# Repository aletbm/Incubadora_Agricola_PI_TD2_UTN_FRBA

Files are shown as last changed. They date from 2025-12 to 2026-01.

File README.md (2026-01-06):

# Incubadora Agrícola Automatica 🐣 

Este proyecto consiste en una **incubadora automatizada** diseñada para optimizar y controlar los parámetros críticos de temperatura y humedad necesarios para la eclosión de huevos de gallina (ciclo de 21 días). Utiliza un sistema embebido basado en **STM32** con **FreeRTOS** para la gestión de tareas en tiempo real y comunicación remota vía **Telegram**.

Desarrollado para la cátedra de **Técnicas Digitales II (2025-R4051) - UTN FRBA**.

---

## 🚀 Características Principales

* **Control Ambiental Automático**: Regulación de temperatura (lámpara halógena) y humedad (humidificador ultrasónico) mediante lógica de histéresis.
* **Ciclo de Incubación Programado**: Gestión automática de las etapas críticas:
    * **Día 0-18 (Incubación)**: Temperatura ~37.7°C, Humedad ~55%, Rotación activa.
    * **Día 18-21 (Eclosión)**: Temperatura ~37.2°C, Humedad ~70%, Rotación detenida.
* **Rotación Automática**: Sistema de bandeja rotatoria por motor para asegurar el desarrollo correcto del embrión.
* **Interfaz de Usuario (HMI)**: Pantalla LCD 16x2 y encoder rotativo KY-040 para navegación de menús.
* **Alertas Remotas**: Notificaciones de alarmas enviadas a un bot de Telegram mediante un módulo ESP32-C3.
* **Persistencia de Datos**: El progreso se guarda en la memoria Flash para retomar el ciclo tras cortes de energía.

---

## 📸 Galería del Proyecto

<p align="center"><i>Vista general del prototipo.</i></p>
<p align="center">
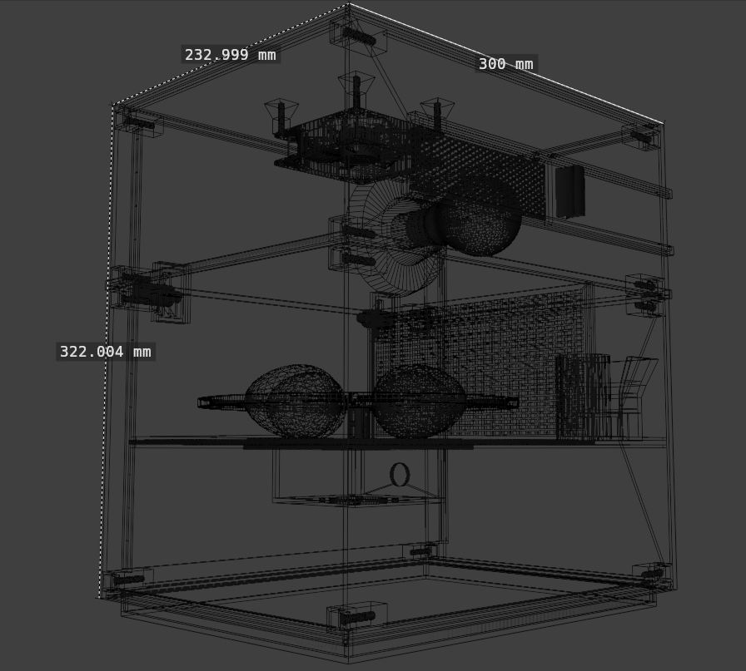
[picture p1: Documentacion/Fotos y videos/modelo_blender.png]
  
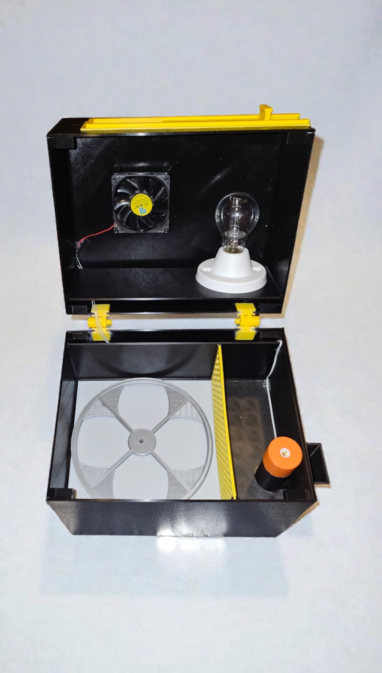
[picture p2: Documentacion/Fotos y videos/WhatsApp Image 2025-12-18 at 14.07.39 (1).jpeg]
  
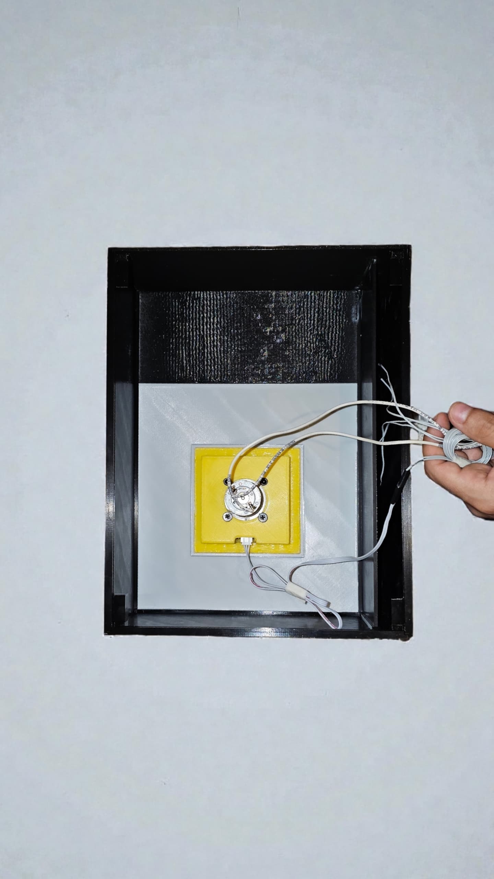
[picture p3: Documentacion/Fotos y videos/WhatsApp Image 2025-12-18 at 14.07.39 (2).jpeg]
Interior de la Incubadora
  
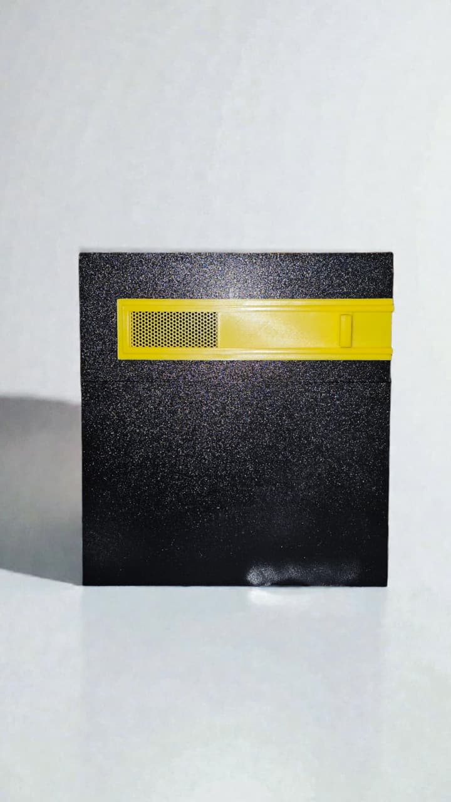
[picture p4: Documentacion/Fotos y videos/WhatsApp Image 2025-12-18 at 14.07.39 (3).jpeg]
Vista Frontal de la incubadora
  
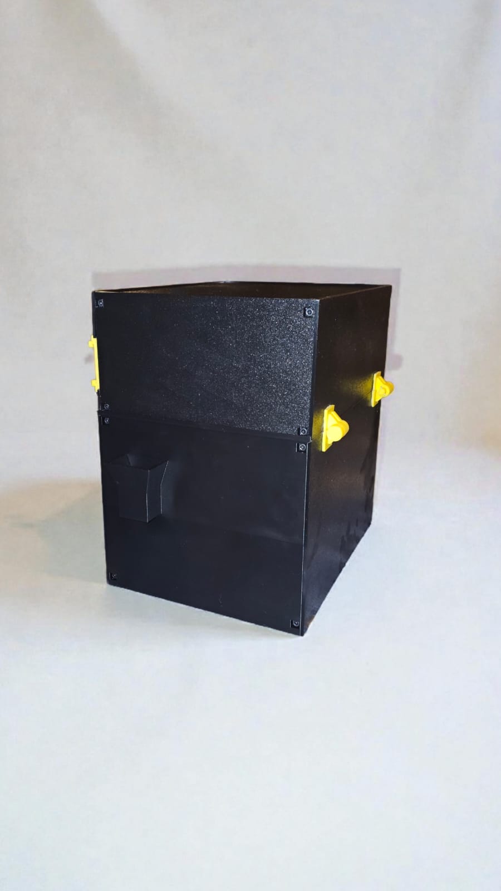
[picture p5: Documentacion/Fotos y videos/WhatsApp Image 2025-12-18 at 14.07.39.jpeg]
Vista oblicua de la Incubadora
  
</p>
<p align="center"><i>Vista del prototipo puesto a prueba.</i></p>

<p align="center">
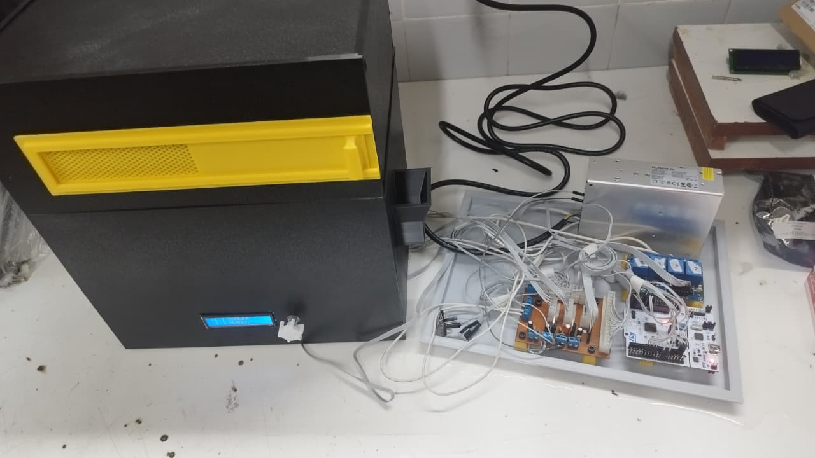
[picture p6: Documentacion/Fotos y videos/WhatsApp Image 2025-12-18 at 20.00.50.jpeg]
  
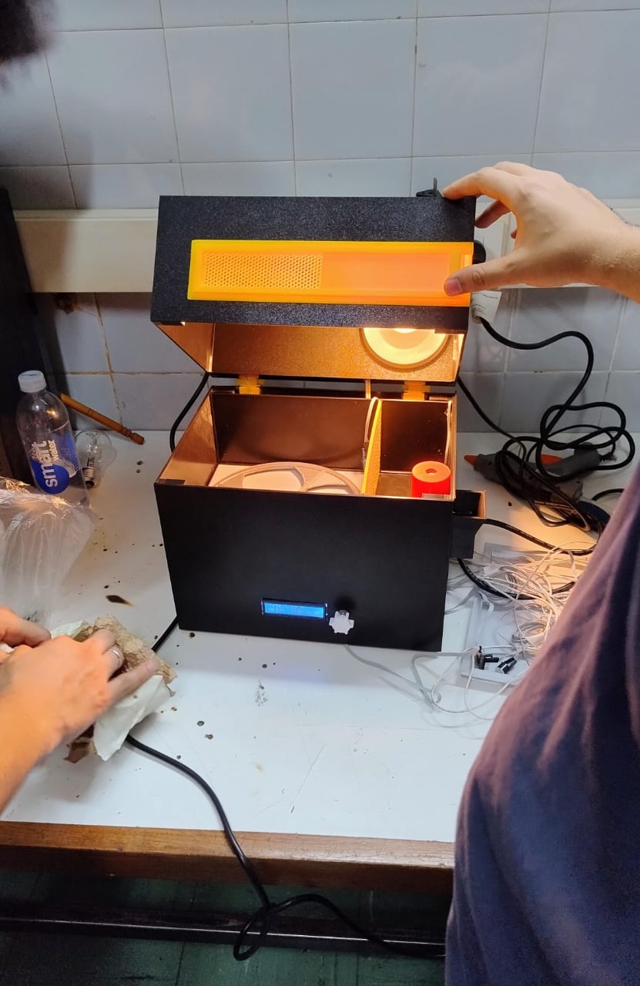
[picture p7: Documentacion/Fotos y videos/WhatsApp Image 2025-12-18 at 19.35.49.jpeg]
  
</p>

<p align="center"><i>Demo de la impresion 3D.</i></p>

https://github.com/user-attachments/assets/dec2215c-aceb-45dd-a1e9-db4e97dc1aad

---

## 🛠️ Hardware y Electrónica

El sistema central utiliza una placa **STM32 Nucleo-F446RE** conectada a un PCB diseñado en KiCad que gestiona tensiones de 3.3V, 5V, 12V y 220V.

### Componentes Clave:
* **Microcontroladores**: STM32F446RE y ESP32-C3 SuperMini (Bridge WiFi).
* **Sensores**: DHT11 para monitoreo ambiental.
* **Actuadores**: Módulo de 4 relés para lámpara, humidificador, cooler y motor.
* **Diseño de PCB**: Realizado íntegramente en **KiCad**.

---

## 💻 Arquitectura de Software (RTOS)

El firmware utiliza **FreeRTOS** para garantizar la ejecución concurrente de tareas críticas:

1.  **menuTask**: Gestión de la interfaz de usuario.
2.  **SensorTask**: Adquisición de datos del sensor DHT11.
3.  **ControlTask**: Lógica de control de temperatura y humedad.
4.  **MotorTask**: Control de tiempos de rotación.
5.  **Telegram/Bridge**: Comunicación serial con el ESP32 para alertas.

---

## 📁 Estructura del Repositorio

* `Incubadora_RTOS/`: Código fuente C para STM32 (STM32CubeIDE).
* `esp32c3-telegram/`: Firmware del módulo WiFi para Telegram.
* `Documentacion/`: Manuales de usuario, técnicos e informes.
* `PCB/`: Archivos de diseño electrónico (**KiCad**).
* `modelo_3D/`: Archivos de **Blender** y piezas **STL** para impresión.
* `Datasheets/`: Hojas de datos de los componentes.

---

## ⚙️ Configuración rápida

1.  **Carga de Firmware**: Flashear el proyecto de la carpeta `Incubadora_RTOS/` en la placa Nucleo.
2.  **Configuración WiFi**: Editar credenciales en `puenteTd2.ino` y cargar al ESP32.
3.  **Uso**: Iniciar el dispositivo, cargar agua en el tanque y seleccionar "INICIAR CICLO" desde el menú.

---

## 👥 Integrantes - Grupo 2
* **Carrettoni, Luciano**
* **Nanni, Franco**
* **Noé, Magdalena Cecilia**
* **Rios, Alexander Daniel**

**UTN FRBA - 2025**

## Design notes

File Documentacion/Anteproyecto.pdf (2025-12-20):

Grupo N°: | 2 | Año y División: | 2025 - R4051
Integrantes: | | 1 - CARRETTONI, LUCIANO 2 - NANNI, FRANCO 3 - NOÉ, MAGDALENA CECILIA 4 - RIOS, ALEXANDER DANIEL
| | Fecha: 25/06/25
Título del Proyecto: | Incubadora Agrícola

## Descripción

El proyecto se enfoca en el desarrollo de una incubadora de huevos de gallina, diseñada para ofrecer un control sobre las condiciones ambientales necesarias para una óptima eclosión. Permitirá a los usuarios configurar y monitorear de manera intuitiva parámetros críticos como la rotación de los huevos, la temperatura interna y la humedad relativa.

A través de su interfaz de usuario, los operadores podrán ajustar con exactitud cada uno de los factores ambientales, adaptándolos a las necesidades específicas de las diferentes etapas de incubación. Este nivel de personalización es crucial para maximizar la tasa de eclosión y asegurar el desarrollo saludable de los embriones.

La incubadora contará con un sistema de registro y almacenamiento de datos. La información detallada sobre los parámetros configurados y las mediciones ambientales se guardará en una tarjeta SD. Esto no solo facilita el monitoreo continuo y el seguimiento del progreso de la incubación, sino que también permite analizar el rendimiento de la incubadora a lo largo del tiempo. Los datos recopilados podrán ser utilizados para identificar patrones, optimizar futuras incubaciones y solucionar posibles problemas, contribuyendo así a una mejora constante en los resultados.

## Proceso

Ciclo de incubación:

El proceso de incubación de un huevo es un proceso que requiere de aproximadamente

### 21 días para concretar su ciclo, durante los cuales se debe mantener al huevo en un

espacio de temperatura y humedad controlada y de esta forma incrementar las probabilidades de una eclosión exitosa.
Dentro de este ciclo existen dos fases donde los parámetros ambientales sufren ligeras modificaciones, la primera fase culmina a los primeros 18 días de iniciar la incubación, donde:
Dia | Eventos principales
0 | Fecundación y formación del blastodisco
1 - 3 | Desarrollo del corazón, vasos sanguíneos, cabeza y ojos
4 - 7 | Formación del pico, alas, patas y plumas

| rudimentarias
8 - 14 | Desarrollo del esqueleto, órganos internos y primeros movimientos
14 - 18 | Posicionamiento del pollito, absorción de la yema y crecimiento final

Durante los últimos 3 días el embrión entra en la fase final durante los cuales se coloca en posición para romper el cascarón, orientando su cabeza hacia la cámara de aire y de esta forma lograr respirar aire a través de dicha cámara, y finalmente logra la eclosión del cascarón.

Los factores que influyen en el éxito de la eclosión involucran los siguiente parámetros:

Temperatura interna
Mantener una temperatura constante y controlada es crítico para el correcto desarrollo embrionario y la eclosión exitosa de los huevos. Este artefacto deberá ser capaz de mantener la temperatura a 37 °C
Consecuencias de errores:
- Temperatura alta: malformaciones, muerte embrionaria
- Temperatura baja: retraso o fallo en la eclosión.

Humedad interna
Durante los primeros 18 días, la humedad se debe mantener de 45% a 55%, y luego de 65% a 75% durante los últimos días antes de la eclosión.
Consecuencias de errores:
Humedad baja: polluelos deshidratados, cáscaras muy duras.
Humedad alta: exceso de líquido en el cascarón, ahogamiento.

Rotación/Inclinación de huevos
Los huevos deben ser rotados o ligeramente inclinados cada 2 o 3 horas durante los primeros 18 días. Los últimos 3 días los huevos no deben ser movidos. Con esto logramos evitar que el embrión se adhiera a la membrana de la cáscara.

Resumen de la variacion de parametros a lo largo del ciclo de incubación:

Periodo | Temperatura
ideal [°C]
Humedad | Movimiento del
huevo

Fase de
incubación

0 - 18 | 37.5 | 50% - 55% | Giro parcial o completo | Desarrollo completo
18 - 21 | 37.2 | 65% - 70% | Sin giro | Preparación y eclosión

## Incubadora

Respecto al diseño de la incubadora, tomamos como referencia ciertos modelos encontrados en internet.

La incubadora consta de un gabinete con aislación
térmica y una tapa superior desmontable, la cual
está equipada con visores para la inspección ocular del proceso. En su interior, una bandeja con sistema de rotación automática alberga los huevos. El ambiente se controla mediante una lámpara halógena para la calefacción y un ventilador que asegura la distribución homogénea de la temperatura y la humedad. Esta última es generada por un humidificador, cuyo depósito puede recargarse desde el exterior y cuenta con un indicador visual de nivel de agua.

El sistema de control electrónico se encuentra en
un | compartimento | separado | para | mayor
seguridad. A través de una pantalla digital, el

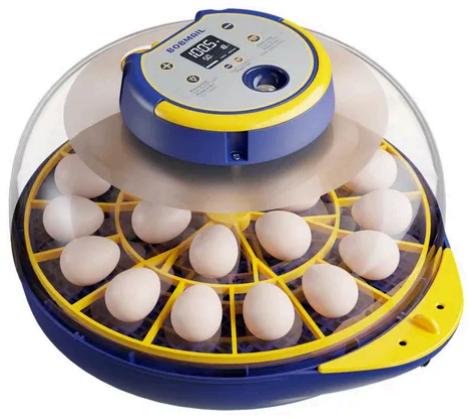
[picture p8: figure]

usuario puede supervisar y modificar los parámetros de incubación.

Además, en casos de emergencia una alarma sonora se activará si la temperatura o la humedad salen de los parámetros normales definidos.

A continuación se presenta un esquema preliminar del diseño.

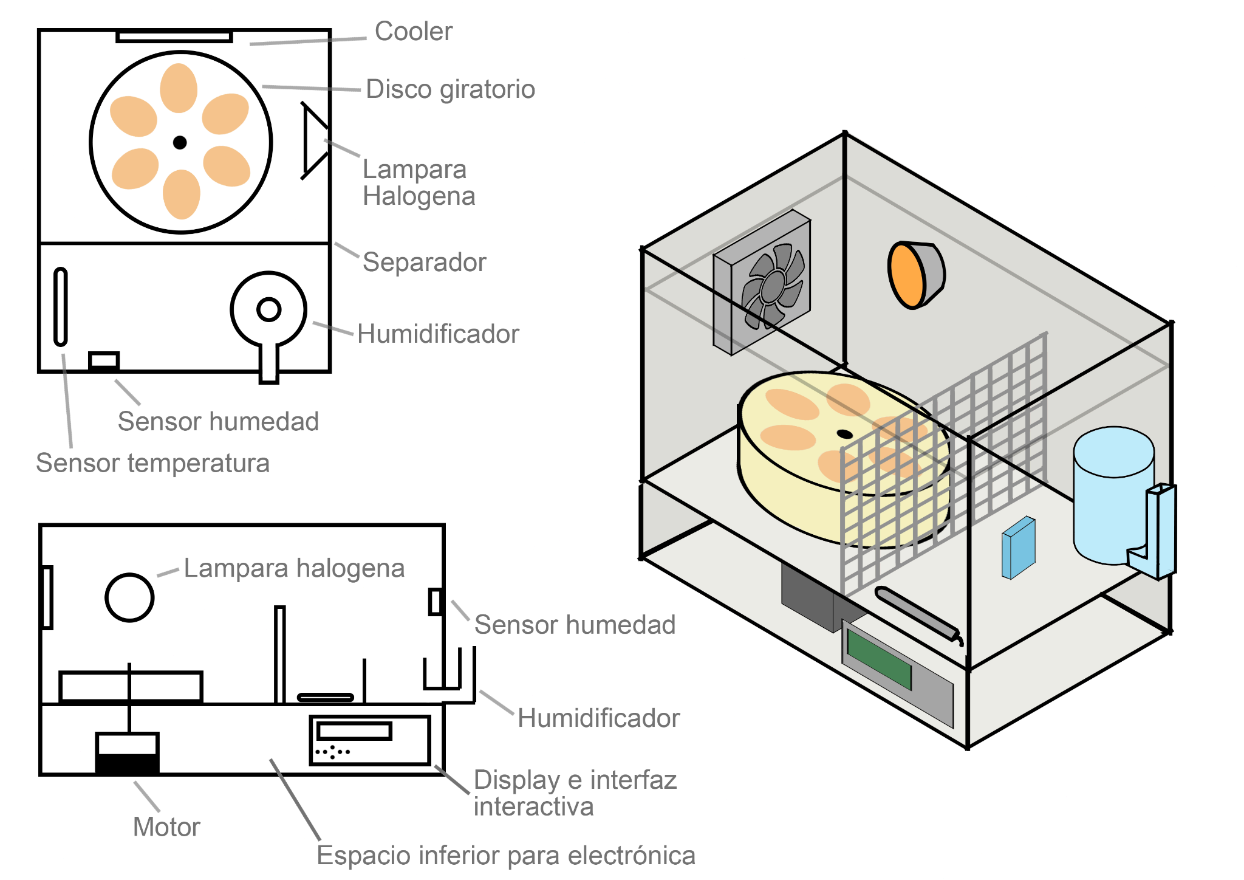
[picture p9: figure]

## Especificación técnica

El equipo contará con los siguientes elementos:
- Microcontrolador STM32F401RE
- Sensor de temperatura PT1000
- Sensor de humedad DHT11
- Motor paso a paso 28byj-48
- Display LCD 16X2 + keypad shield (botonera).
- Modulo tarjeta SD EM2003
- Fuente de alimentación
- Módulo relé
- Cooler.
- Lámpara halógena
- Humidificador
- Buzzer.

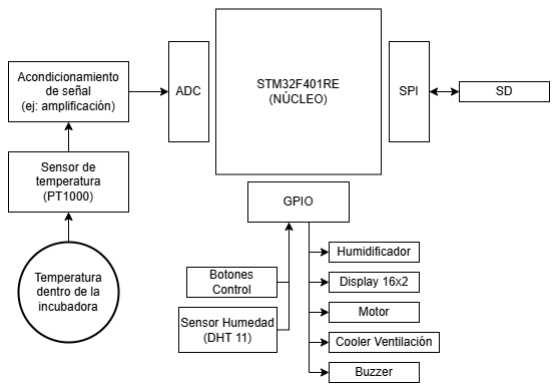
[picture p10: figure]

Motor 28BYJ-48 paso a paso, unipolar

Tensión de Funcionamiento: 5V DC Driver: ULN2003
Relación de Reducción: 1/64
Pasos por Vuelta: 4096
Par:34.3 mN·m

La selección del motor paso a paso 28BYJ-48 para el mecanismo de rotación se justifica por su capacidad para cumplir con los requerimientos de la aplicación económica. Este motor proporciona un torque de 34.3 mN·m, el cual es amplificado significativamente por el diseño del sistema. Tras calcular la carga máxima considerando un peso de 420 g para seis huevos y 300 g para la bandeja (total 0.72 kg) y estimar la fuerza de fricción, se determinó que se necesitaría un torque de aproximadamente 224 mN·m para mover la bandeja directamente.

Sin embargo, el diseño incorpora un sistema de engranajes externo (piñón-corona) que ofrece una ventaja mecánica de aproximadamente 20:1. Esta reducción reduce el par requerido en el eje del motor a solo 11.2 mN·m, un valor que es ampliamente cubierto por la capacidad del motor seleccionado, garantizando así un funcionamiento fiable con un margen de fuerza considerable.

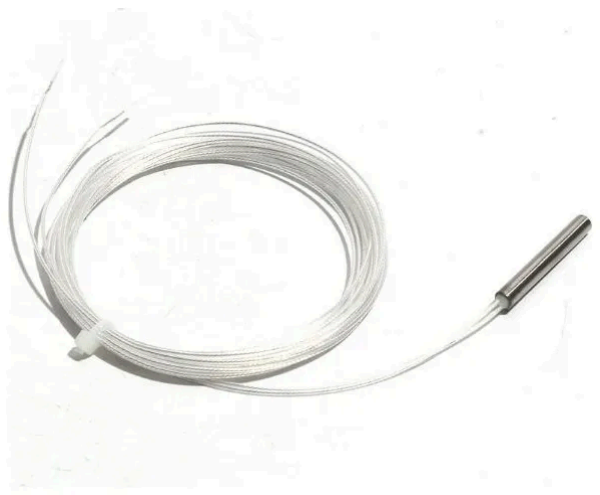
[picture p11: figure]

PT100: Sensor de temperatura
Rango típico de operación: -200 °C a 85°C
Precisión: 0.15°C (Clase A)
Tipo de señal: Analógica

DHT11: Sensor de humedad
Tensión de Operación: 3,3 - 5V DC
Rango de medición de temperatura: 0 a 50 °C Precisión de medición de temperatura: ±2.0 °C Resolución: 0.1°C
Rango de medición de humedad: 20% a 90% RH. Precisión de medición de humedad: 4% RH.
Resolución Humedad: 1% RH
Frecuencia de sensado: 2 seg.

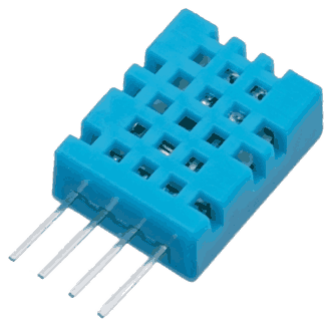
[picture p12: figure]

Transmisión de datos de 40 bits, el sensor envía el primer bit de datos en 1.
Formato de datos: 8 bits de datos RH enteros + 8 bits de datos RH decimales + 8 bits de datos T enteros + 8 bits de datos T decimales + 8 bits de checkSum.

EM2003: Modulo tarjeta SD
Interfaz de comunicación SPI estándar Alimentación: 4,5-5,5 V
Consumo: 0,2-200 mA
Nivel de interfaz: 3,3 o 5 V
Tarjetas compatibles: Micro SD (<=2 GB), Micro SDHC (<=32 GB)

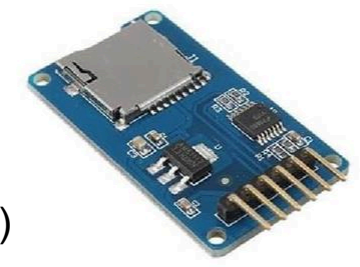
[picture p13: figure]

Interfaz de control: Seis pines (GND, VCC, MISO, MOSI, SCK, CS)

Timestamp propuesta: fecha y hora relativa de ciclo de eclosión, temperatura, humedad y estado de actuadores.

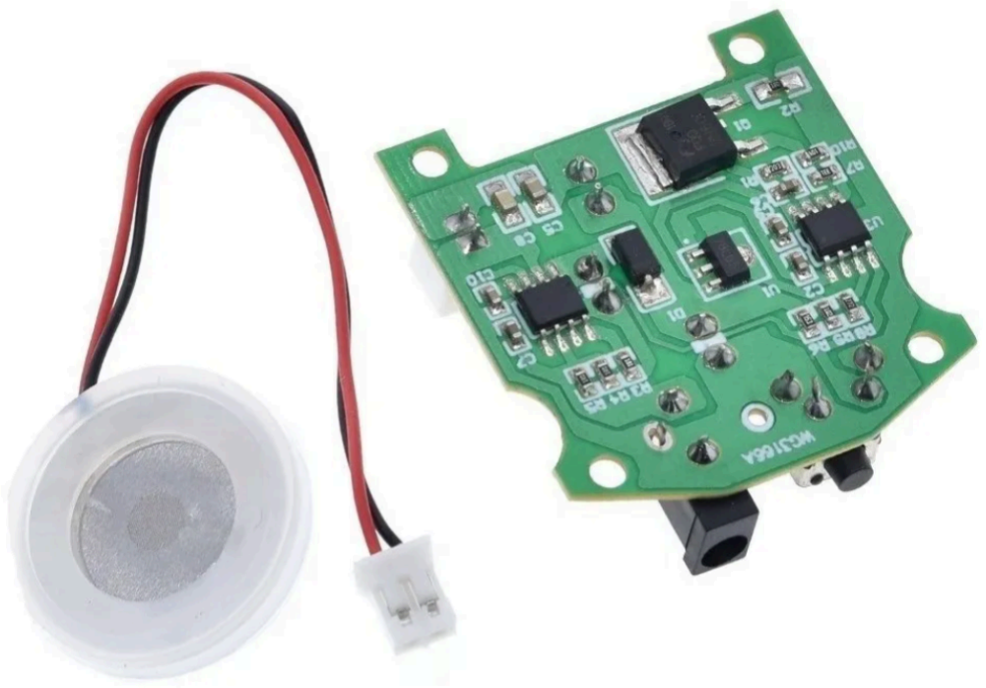
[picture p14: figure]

Humidificador ultrasónico:
Tensión de funcionamiento: 3.7V a 12V DC Frecuencia: 113 KHz

Si bien este humidificador se activa mediante
un pulsador, se modificará para ser activado por una señal desde el microcontrolador.

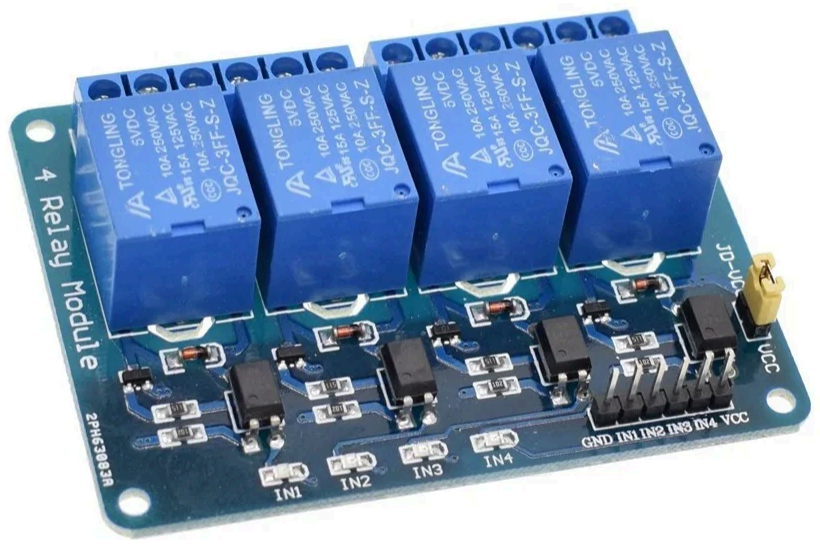
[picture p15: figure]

Módulo Relé

Optoacoplado
Alimentación, 5V
Funcionamiento, Activo en bajo

Este módulo será utilizado para controlar la lámpara halógena y ventiladores.

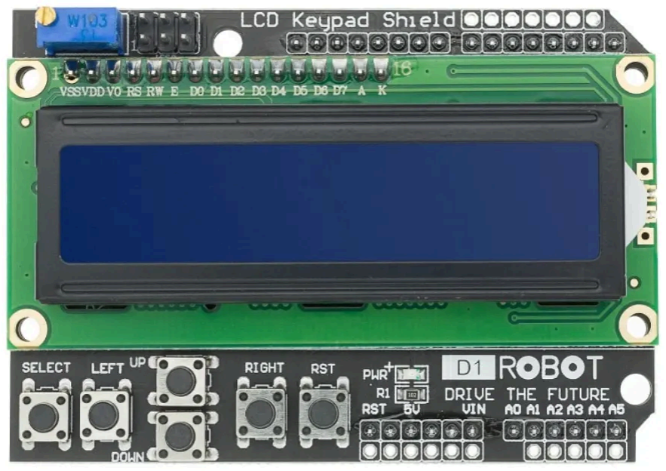
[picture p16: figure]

Display 16x2

Alimentación, 5V
Consumo, 30 mA
Driver HD44780,
Comunicación paralela 4/8 Bits

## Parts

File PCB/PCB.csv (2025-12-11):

Reference | Qty | Value | DNP | Exclude from BOM | Exclude from Board | Footprint | Datasheet
C1 | 1 | 0.33uF |  |  |  | Capacitor_THT:CP_Radial_D5.0mm_P2.50mm | ~
C2,C4,C6,C8 | 4 | 0.1uF |  |  |  | Capacitor_THT:C_Disc_D3.0mm_W1.6mm_P2.50mm | ~
C3,C5,C7 | 3 | 10uF |  |  |  | Capacitor_THT:CP_Radial_D4.0mm_P2.00mm | ~
D1 | 1 | 1N5819 |  |  |  | Diode_THT:D_DO-41_SOD81_P10.16mm_Horizontal | http://www.vishay.com/docs/88525/1n5817.pdf
J1 | 1 | 12V_IN |  |  |  | TerminalBlock:TerminalBlock_MaiXu_MX126-5.0-02P_1x02_P5.00mm | ~
J2 | 1 | 5V_OUT |  |  |  | TerminalBlock:TerminalBlock_MaiXu_MX126-5.0-02P_1x02_P5.00mm | ~
J3 | 1 | DHT11 |  |  |  | Connector_Molex:Molex_KK-396_5273-03A_1x03_P3.96mm_Vertical | ~
J4 | 1 | Buzzer |  |  |  | Connector_Molex:Molex_KK-396_5273-02A_1x02_P3.96mm_Vertical | ~
J5 | 1 | TX |  |  |  | Connector_Molex:Molex_KK-396_5273-03A_1x03_P3.96mm_Vertical | ~
J6 | 1 | Humidi. |  |  |  | Connector_Molex:Molex_KK-396_5273-02A_1x02_P3.96mm_Vertical | ~
J7 | 1 | Cooler |  |  |  | Connector_Molex:Molex_KK-396_5273-02A_1x02_P3.96mm_Vertical | ~
J8 | 1 | Nucleo |  |  |  | Connector_Molex:Molex_KK-396_A-41791-0015_1x15_P3.96mm_Vertical | ~
J9 | 1 | 9V_OUT |  |  |  | TerminalBlock:TerminalBlock_MaiXu_MX126-5.0-02P_1x02_P5.00mm | ~
J10 | 1 | Retorno_1 |  |  |  | TerminalBlock:TerminalBlock_MaiXu_MX126-5.0-02P_1x02_P5.00mm | ~
J11 | 1 | Modulo_Reles |  |  |  | Connector_PinHeader_2.54mm:PinHeader_1x06_P2.54mm_Vertical | ~
J12 | 1 | Motor |  |  |  | TerminalBlock:TerminalBlock_MaiXu_MX126-5.0-02P_1x02_P5.00mm | ~
J13 | 1 | Retorno_2 |  |  |  | TerminalBlock:TerminalBlock_MaiXu_MX126-5.0-02P_1x02_P5.00mm | ~
J14 | 1 | 3_3V_OUT |  |  |  | TerminalBlock:TerminalBlock_MaiXu_MX126-5.0-02P_1x02_P5.00mm | ~
J15 | 1 | Encoder_Rotativo |  |  |  | Connector_Molex:Molex_KK-396_5273-05A_1x05_P3.96mm_Vertical | ~
J16 | 1 | Encoder_Motor |  |  |  | Connector_Molex:Molex_KK-396_5273-03A_1x03_P3.96mm_Vertical | ~
J17 | 1 | LCD |  |  |  | Connector_Molex:Molex_KK-396_5273-04A_1x04_P3.96mm_Vertical | ~
U1 | 1 | LM7805_TO220 |  |  |  | Package_TO_SOT_THT:TO-220-3_Vertical | https://www.onsemi.cn/PowerSolutions/document/MC7800-D.PDF
U2 | 1 | LM7809_TO220 |  |  |  | Package_TO_SOT_THT:TO-220-3_Vertical | https://www.onsemi.cn/PowerSolutions/document/MC7800-D.PDF
U3 | 1 | LD1117V33 |  |  |  | Package_TO_SOT_SMD:SOT-223 | https://www.st.com/resource/en/datasheet/ld1117.pdf

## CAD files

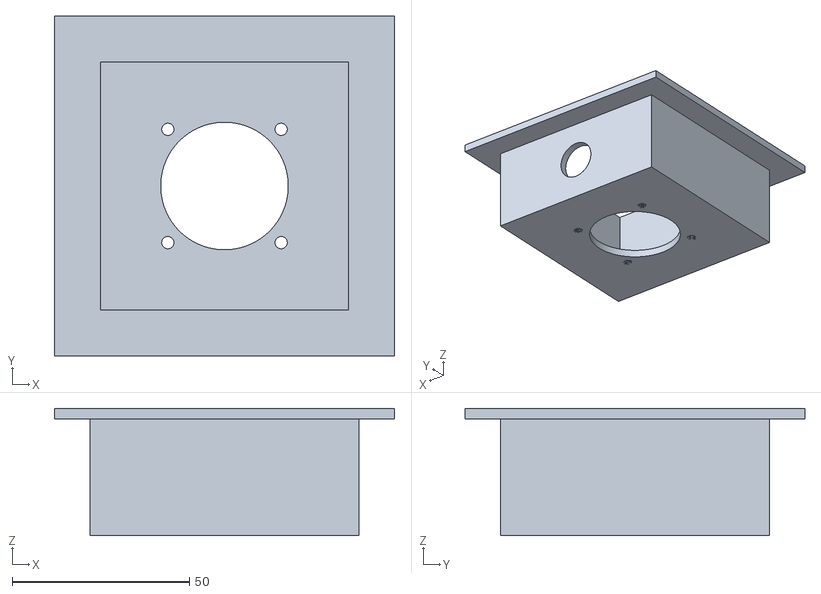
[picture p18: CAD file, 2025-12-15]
modelo_3D/imprimibles/Accesorios/Soporte_motor.stl
96.0 x 96.0 x 36.0

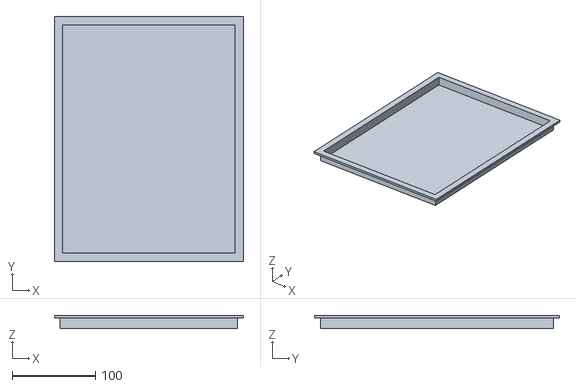
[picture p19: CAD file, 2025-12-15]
modelo_3D/imprimibles/Caja_Inferior/Base.stl
227.0 x 294.0 x 16.0

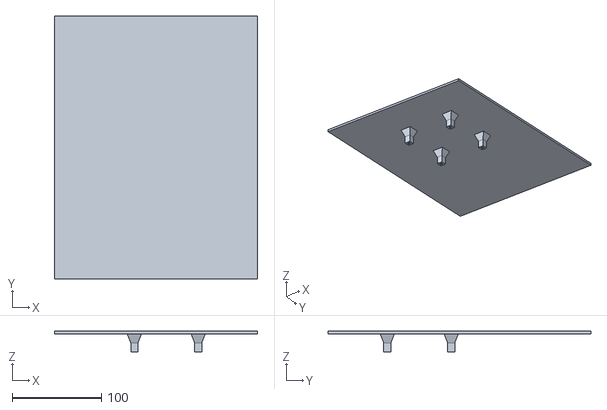
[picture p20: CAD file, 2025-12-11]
modelo_3D/imprimibles/Caja_Superior/Pared_techo.stl
227.0 x 294.0 x 23.0

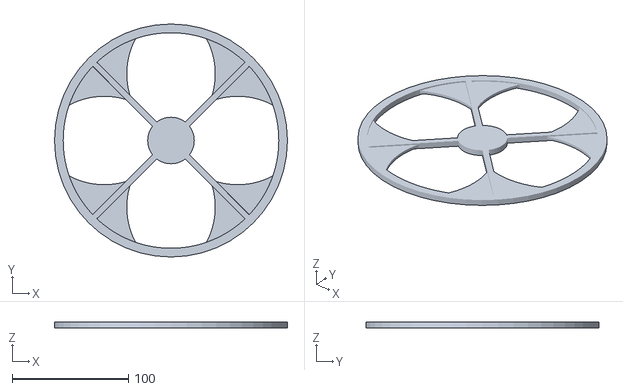
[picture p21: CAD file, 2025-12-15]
modelo_3D/imprimibles/Accesorios/carrousel.stl
200.1 x 200.1 x 4.91

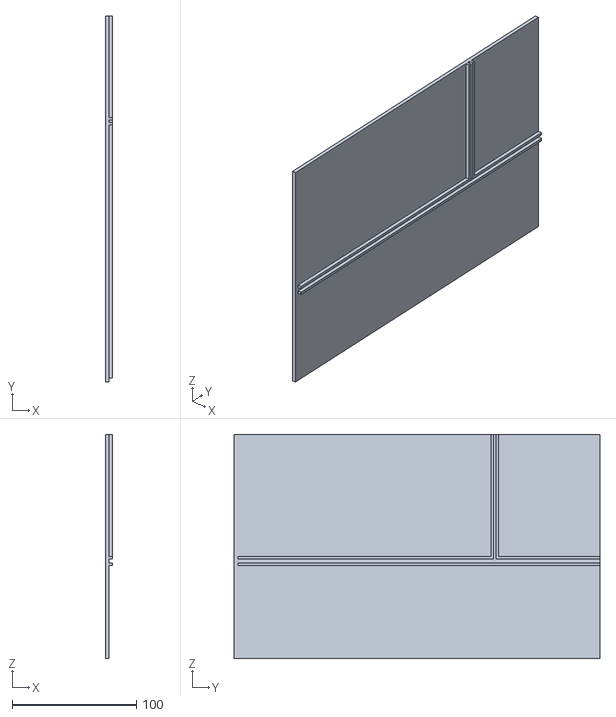
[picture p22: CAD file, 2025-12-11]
modelo_3D/imprimibles/Caja_Inferior/Pared_Interna.stl
6.00 x 294.0 x 180.0

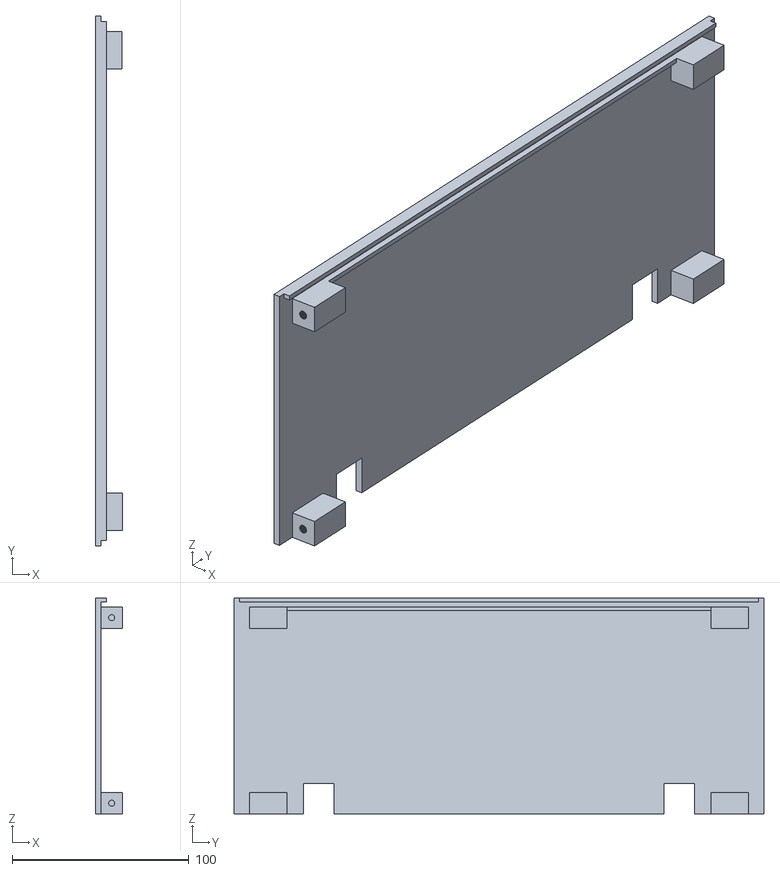
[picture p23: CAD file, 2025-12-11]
modelo_3D/imprimibles/Caja_Superior/Pared2.stl
15.0 x 300.0 x 122.0

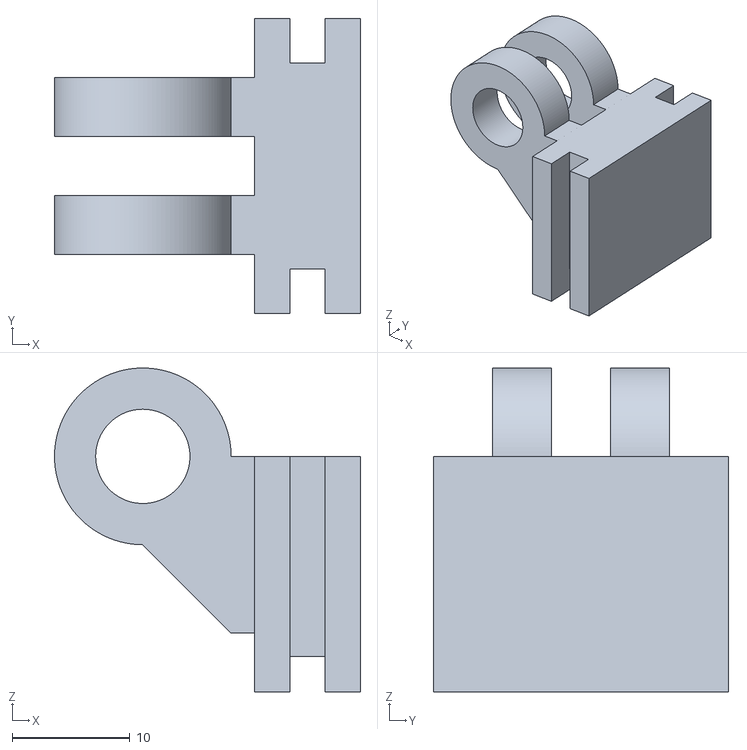
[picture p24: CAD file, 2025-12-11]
modelo_3D/imprimibles/Accesorios/Visagra_inferiorx2.stl
26.0 x 25.0 x 27.5

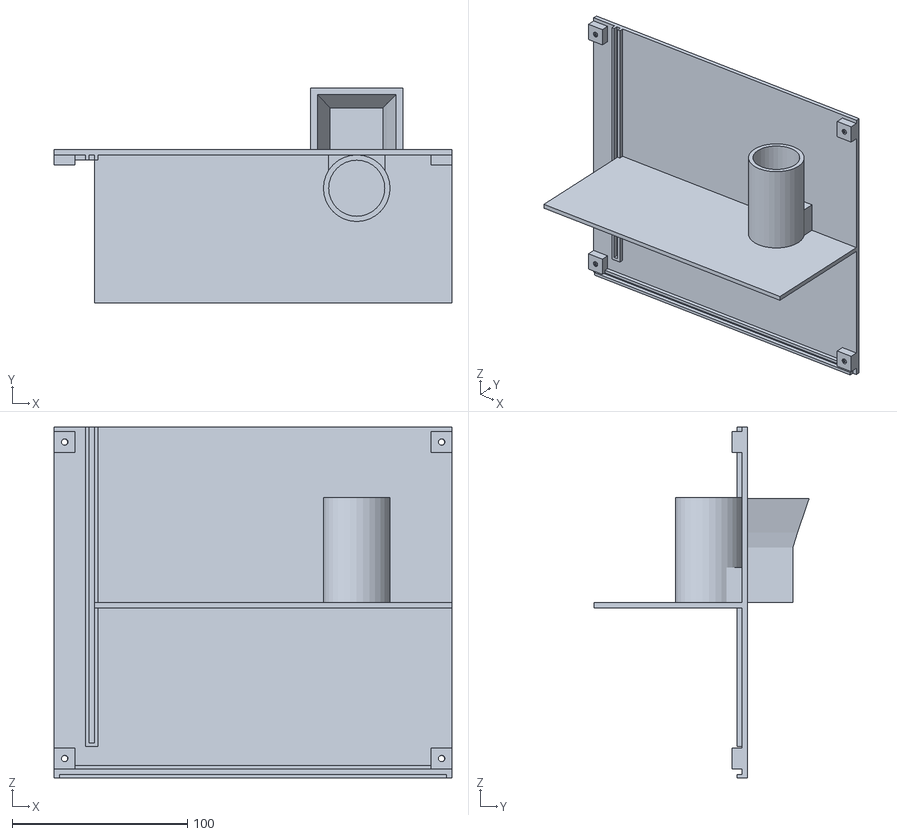
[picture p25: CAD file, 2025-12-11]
modelo_3D/imprimibles/Caja_Inferior/Pared1.stl
227.0 x 122.9 x 200.0

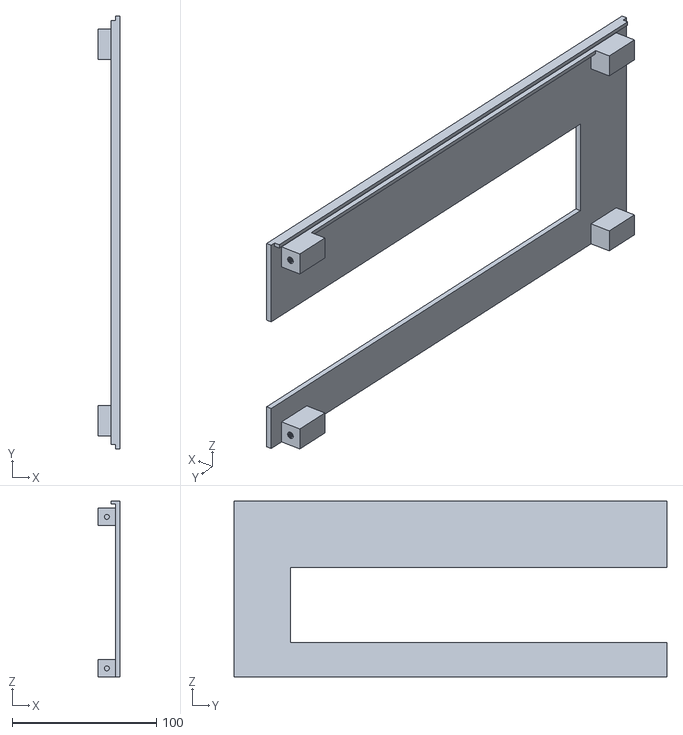
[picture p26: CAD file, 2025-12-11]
modelo_3D/imprimibles/Caja_Superior/Pared4.stl
15.0 x 300.0 x 122.0

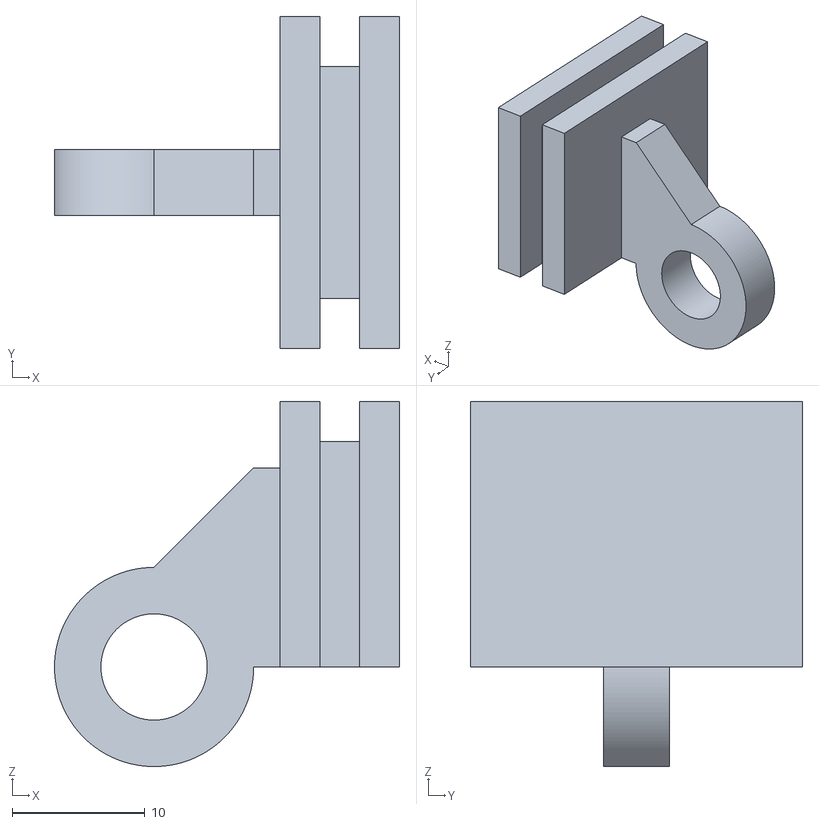
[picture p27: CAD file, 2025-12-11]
modelo_3D/imprimibles/Accesorios/Visagra_superiorx2.stl
26.0 x 25.0 x 27.5

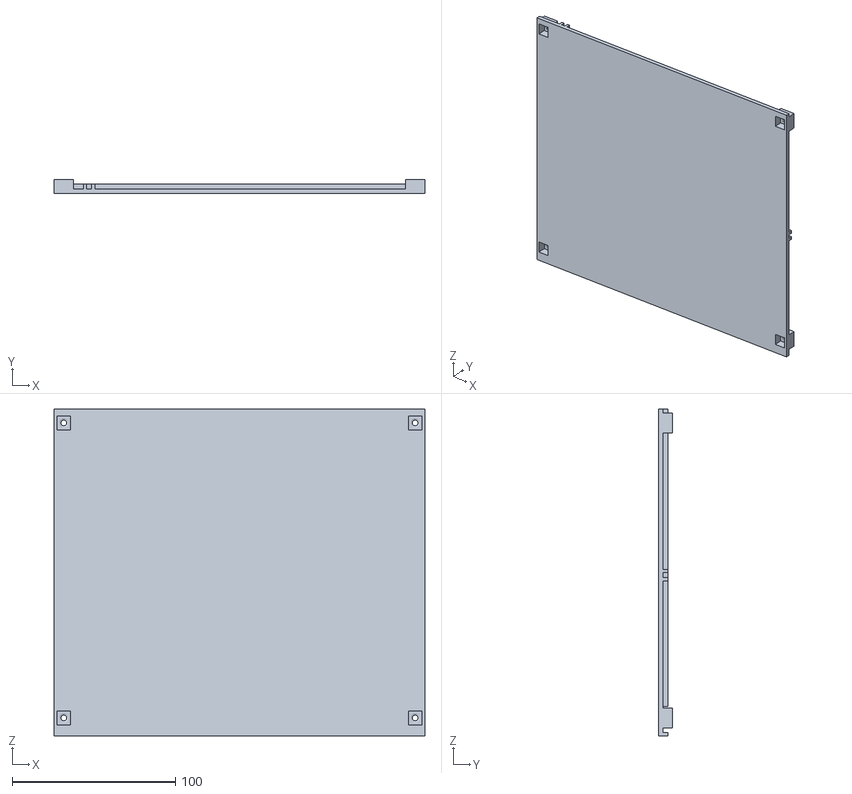
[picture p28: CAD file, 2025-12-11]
modelo_3D/imprimibles/Caja_Inferior/Pared3.stl
227.0 x 8.79 x 200.0

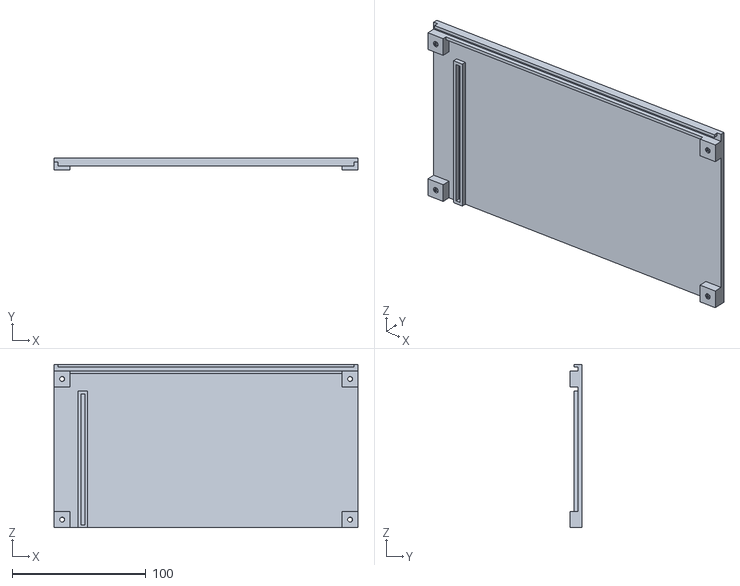
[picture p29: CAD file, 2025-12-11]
modelo_3D/imprimibles/Caja_Superior/Pared3.stl
227.0 x 8.79 x 122.0

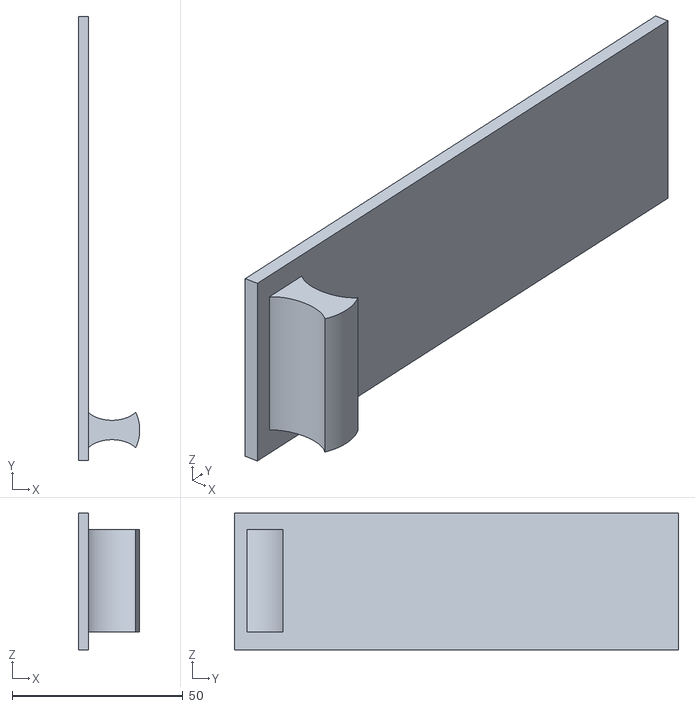
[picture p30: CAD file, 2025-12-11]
modelo_3D/imprimibles/Accesorios/Puerta.stl
18.0 x 130.0 x 40.0

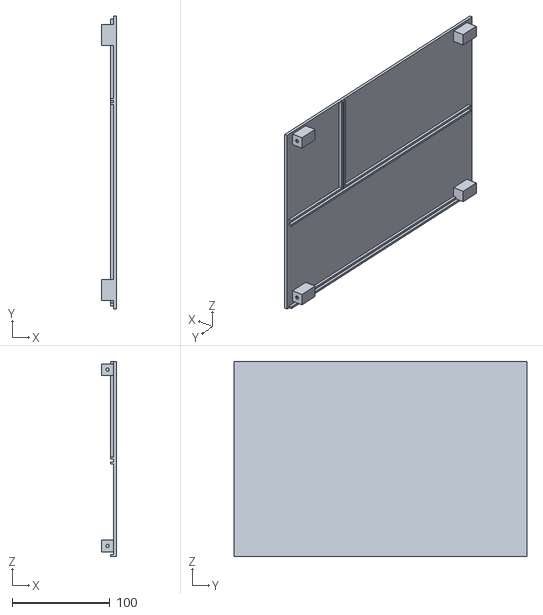
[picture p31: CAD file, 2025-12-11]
modelo_3D/imprimibles/Caja_Inferior/Pared2.stl
15.0 x 300.0 x 200.0

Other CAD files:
modelo_3D/imprimibles/Caja_Superior/Pared1.stl
modelo_3D/imprimibles/Accesorios/Marco_ventana.stl
modelo_3D/imprimibles/Caja_Inferior/Pared4.stl
modelo_3D/imprimibles/Caja_Superior/Pared_lampara.stl
modelo_3D/imprimibles/Accesorios/Grilla.stl
modelo_3D/imprimibles/Accesorios/Grilla_ventana.stl
modelo_3D/imprimibles/Accesorios/Trabax2.stl

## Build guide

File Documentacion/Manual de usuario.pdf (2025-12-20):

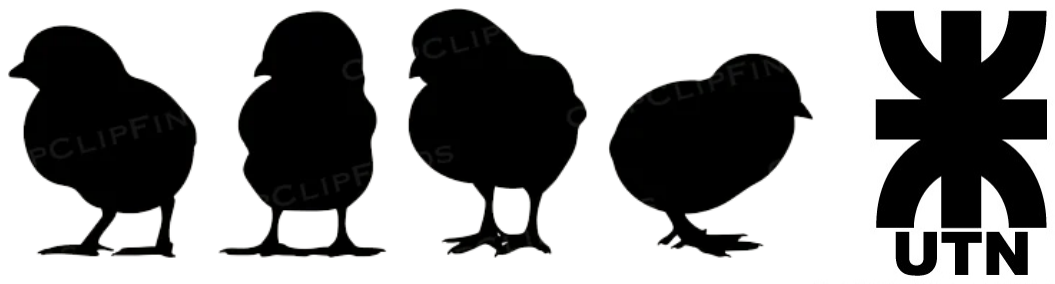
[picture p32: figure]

# Incubadora Inteligente

## Manual de usuario

Este dispositivo está diseñado para crear y mantener las condiciones óptimas de temperatura y humedad para incubar huevos de gallina de forma automática. Con funciones de rotación automática de huevos, monitoreo constante y alertas remotas a su teléfono. Simplemente se deben colocar huevos fecundados en su interior, mantener el tanque de agua para el humidificador cargado, ¡Y en 21 los huevos comenzarán a eclosionar!

# Contenido

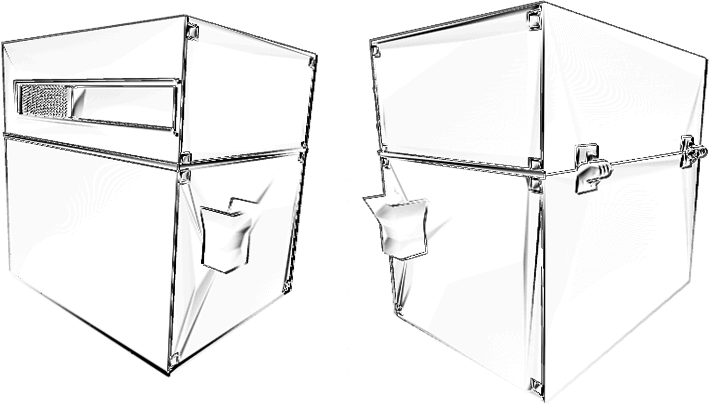
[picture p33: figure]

- Descripción del Equipo
- Instalación y Primeros Pasos
- Encendido
- Empezar a incubar
- ¿Cómo son incubados los pollitos?
- Navegación por el Menú
- Apagado del Dispositivo
- Conexion WiFi
- Mantenimiento
- Solución de Problemas
- Soporte Técnico

# Descripción del Equipo

Su incubadora cuenta con los siguientes elementos:
- Cuerpo Principal: Cofre que contiene todos los elementos de la incubadora.
- Bandeja rotatoria: En esta bandeja circular, que se encuentra dentro de la incubadora, colocara los huevos fecundados.
- Separador interno: Para la protección de los pollos que hayan eclosionado la incubadora cuenta con un divisor entre la bandeja que contendrá los huevos, y la lámpara y humidificador.
- Pantalla LCD: Se encuentra en el exterior. Muestra la temperatura, humedad, día de incubación y estado del sistema.
- Selector (Perilla Giratoria): Rotar el mismo para navegar el menú y pulsar sobre la perilla para abrir o seleccionar el menú marcado.
- Entrada de agua: Orificio lateral para rellenar el humidificador sin abrir la incubadora y alterar las condiciones de incubación.
- Puerto de Alimentación: Para conectar el cable de poder a un enchufe 220V.
- Ventilación: Pequeño ventilador que regula la temperatura y humedad interna.
- Lámpara interna: Para obtener la temperatura adecuada.

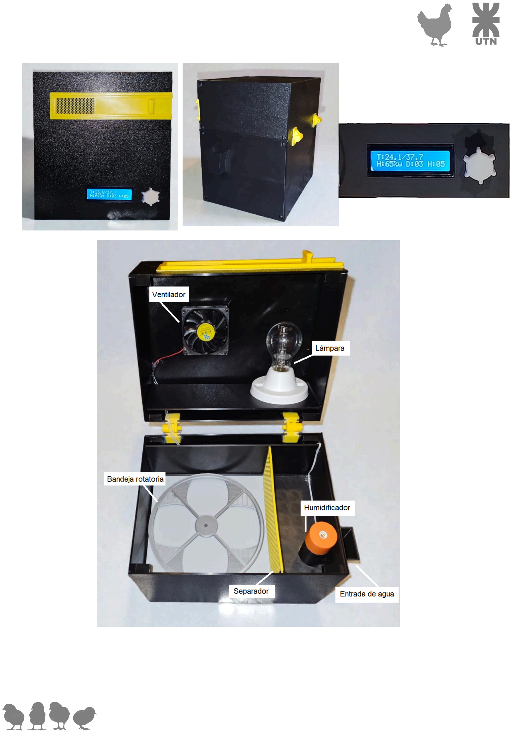
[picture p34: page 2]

# Instalación y Primeros Pasos

Antes de usar por primera vez verifique colocar la incubadora en una superficie plana y estable, alejada de corrientes de aire, ventanas con sol directo o fuentes de calor y frío. Conecte el cable de poder al puerto de la incubadora y luego a un tomacorriente de 220V. Utilice agua limpia (preferiblemente destilada) para llenar el depósito del humidificador a través de la entrada lateral. Esta puede llenarse hasta el borde.

# Encendido

Al conectar la incubadora a la corriente, el sistema se iniciará automáticamente. Verá un mensaje de bienvenida en la pantalla. A continuación la pantalla mostrará información sobre: temperatura actual y temperatura ideal. Humedad actual. Día y hora del ciclo.

# Empezar a incubar

Coloque huevos fecundados en el interior de la incubadora, dentro del disco circular. Gire el selector para desplazar el cursor (>) hasta "INICIAR CICLO".
Presione el botón del selector para confirmar. El sistema comenzará el conteo del día 1 y activará la autorregulación de parámetros.
Para más información refiérase al apartado “Navegación por el Menú”.

# ¿Cómo son incubados los pollitos?

El proceso de incubación es de aproximadamente 21 días en total, durante los cuales se debe mantener al huevo en un espacio de temperatura y humedad controlada y de esta forma incrementar las probabilidades de una eclosión exitosa. Dentro de estos los pollitos atravesaran las siguientes etapas de desarrollo:

Día 0 | Fecundación y formación del blastodisco
Días 1 - 3 | Desarrollo del corazón, vasos sanguíneos, cabeza y ojos
Días 4 - 7 | Formación del pico, alas, patas y plumas rudimentarias
Días 8 - 14 | Desarrollo del esqueleto, órganos internos y primeros movimientos
Días 14 - 18 | Posicionamiento del pollito, absorción de la yema y crecimiento final
Dias 19 - Final | Visite a diario la incubadora durante este periodo. Los huevos pueden tener una diferencia de eclosión entre sí de hasta 48 horas.

Los huevos fecundados deben encontrarse en las siguientes condiciones:

Periodo | Temperatura ideal [°C] | Humedad | Movimiento del huevo | Fase de incubación
0 - 18 | 37.5 | 50% - 55% | Giro parcial o completo | Desarrollo completo
18 - 21 | 37.2 | 65% - 70% | Sin giro | Preparación y eclosión

La incubadora inteligente se encarga de autorregular estas condiciones, para asegurar una incubación óptima. Esta cuenta con las siguientes capacidades:
- Control Climático: Mide constantemente la temperatura y humedad. Enciende la lámpara si hace frío, el ventilador si hace calor, y el humidificador si el aire está seco.
- Rotación de huevos: El motor girará la bandeja periódicamente para evitar que los embriones se adhieran al cascarón.
- Panel de Control: La pantalla siempre mostrará los valores actuales

# Navegación por el Menú

La incubadora cuenta con una pequeña pantalla, la cual siempre estará mostrando la siguiente información:
Temperatura actual y objetivo T:24.1/37.7
Humedad actual H:65%
Estado control de humedad (* -> Humidificando / w -> En enfriamiento) Dia y hora del ciclo de incubación D:03 H:05

T:24.1/37.7

## H:65%w D:03 H:05

Desde esta pantalla puede presionar la perilla como un botón para entrar al Menú. Aquí navegue con el selector (>) girando la perilla. Tendrá las opciones:
- Ver Sensores Vuelve a la pantalla principal
- Ciclo: INICIAR/PAUSAR Inicia un nuevo ciclo o pausa el actual.
- PAUSAR CICLO
- INICIAR CICLO
- Configuracion
- CFG: Desarrollo: Ajusta objetivos para los primeros 18 días.
- CFG: Eclosión: Ajusta objetivos para los últimos 3 días.
- Ciclo Total: Cambia la duración total (por defecto 21 días).
- Ajustar Tiempo: Permite corregir manualmente el día y hora actual del ciclo.
- Volver <- Retorna al menú
- TEST Utilizar solo bajo supervisión de un profesional. Permite apagar manualmente y de forma individual el cooler, humidificador, luz y motor.

# Apagado del Dispositivo

Pausa o Fin de Ciclo: Si desea detener el proceso (para revisar huevos o finalizar), vaya a Menú Principal > PAUSAR CICLO. Los controles se detendrán pero la configuración se guardará.

Apagado Total
Desconecte el cable de alimentación de la toma de corriente. Se recomienda pausar el ciclo primero desde el menú.

# Conexión WiFi

La incubadora se iniciará sin conexión wifi. Para que esta pueda enviarle advertencias a su celular deberá conectarse a la red WiFi “AP”. Allí será direccionado a un portal en el cual debe entrar a “Configure WiFi” e ingresar el nombre y contraseña de su red WiFi.

Felicidades, ahora su incubadora podrá enviarle mensajes directos a su cuenta de Telegram por medio del chat con @incubadora_td2_bot.

# Mantenimiento

Limpieza

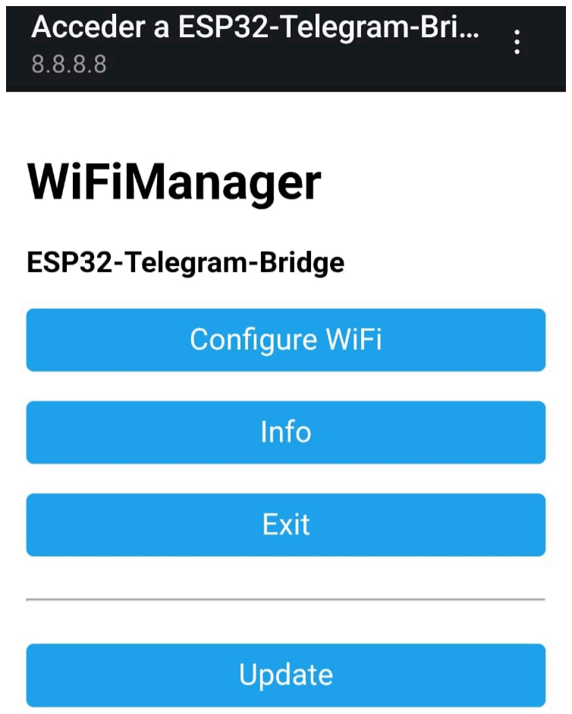
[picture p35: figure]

Antes y después de cada uso, limpie el interior con un paño húmedo. No use productos químicos abrasivos.
Puede retirar la bandeja contenedora de huevos para su fácil lavado. Se recomienda agua tibia y jabón suave.
Agua
Revise el nivel de agua cada 2 días y rellene si es necesario. Vacíe y seque completamente el depósito al finalizar cada ciclo o antes de mover el dispositivo.
Ventilación
Asegúrese de que las rejillas de ventilación no estén obstruidas y que el ventilador pueda girar libremente.
Lamparita
En caso de que la lámpara de calor deje de funcionar reemplazarla por una estándar de 100W.

# Solución de Problemas

Problema | Posible Causa | Solución
Pantalla no enciende | Sin energía. | Verifique que el cable esté bien conectado a la red y a la incubadora.
Temperatura/Humedad incorrecta | Sensor bloqueado, puertas mal cerradas, lamparita quemada. | Asegure que la tapa esté bien sellada y que nada tape el sensor interno. Espere 1 hora a que se autorregule. Reemplazar lamparita.
Buzzer suena continuamente | ALARMA. Parámetro fuera de rango por más de 2 minutos.
1. Revise la pantalla para
| | ver qué parámetro falla (Temp o Hum).
2. Verifique que la tapa esté
| | cerrada, que haya agua y que no haya un fallo eléctrico.
3. Si la lamparita no se
| | enciende reemplazarla por una nueva (100W)
Motor no gira | Obstrucción o falla. | Apague la incubadora, retire los huevos y verifique que la bandeja gire libremente. Reinicie.
Recibo alertas en Telegram | El sistema detectó una condición que no pudo corregir. | Revise la pantalla de la incubadora. Las alertas indican que requiere su atención. Siga las instrucciones del mensaje.

Soporte Técnico
Si después de revisar la guía de solución de problemas el equipo no funciona correctamente comuníquese con el soporte técnico del fabricante por https://frba.utn.edu.ar/
Tenga a mano el modelo de la incubadora y describa el problema con detalle (qué muestra la pantalla, sonidos, etc.).

¡No desarme el equipo! La apertura no autorizada invalida la garantía.

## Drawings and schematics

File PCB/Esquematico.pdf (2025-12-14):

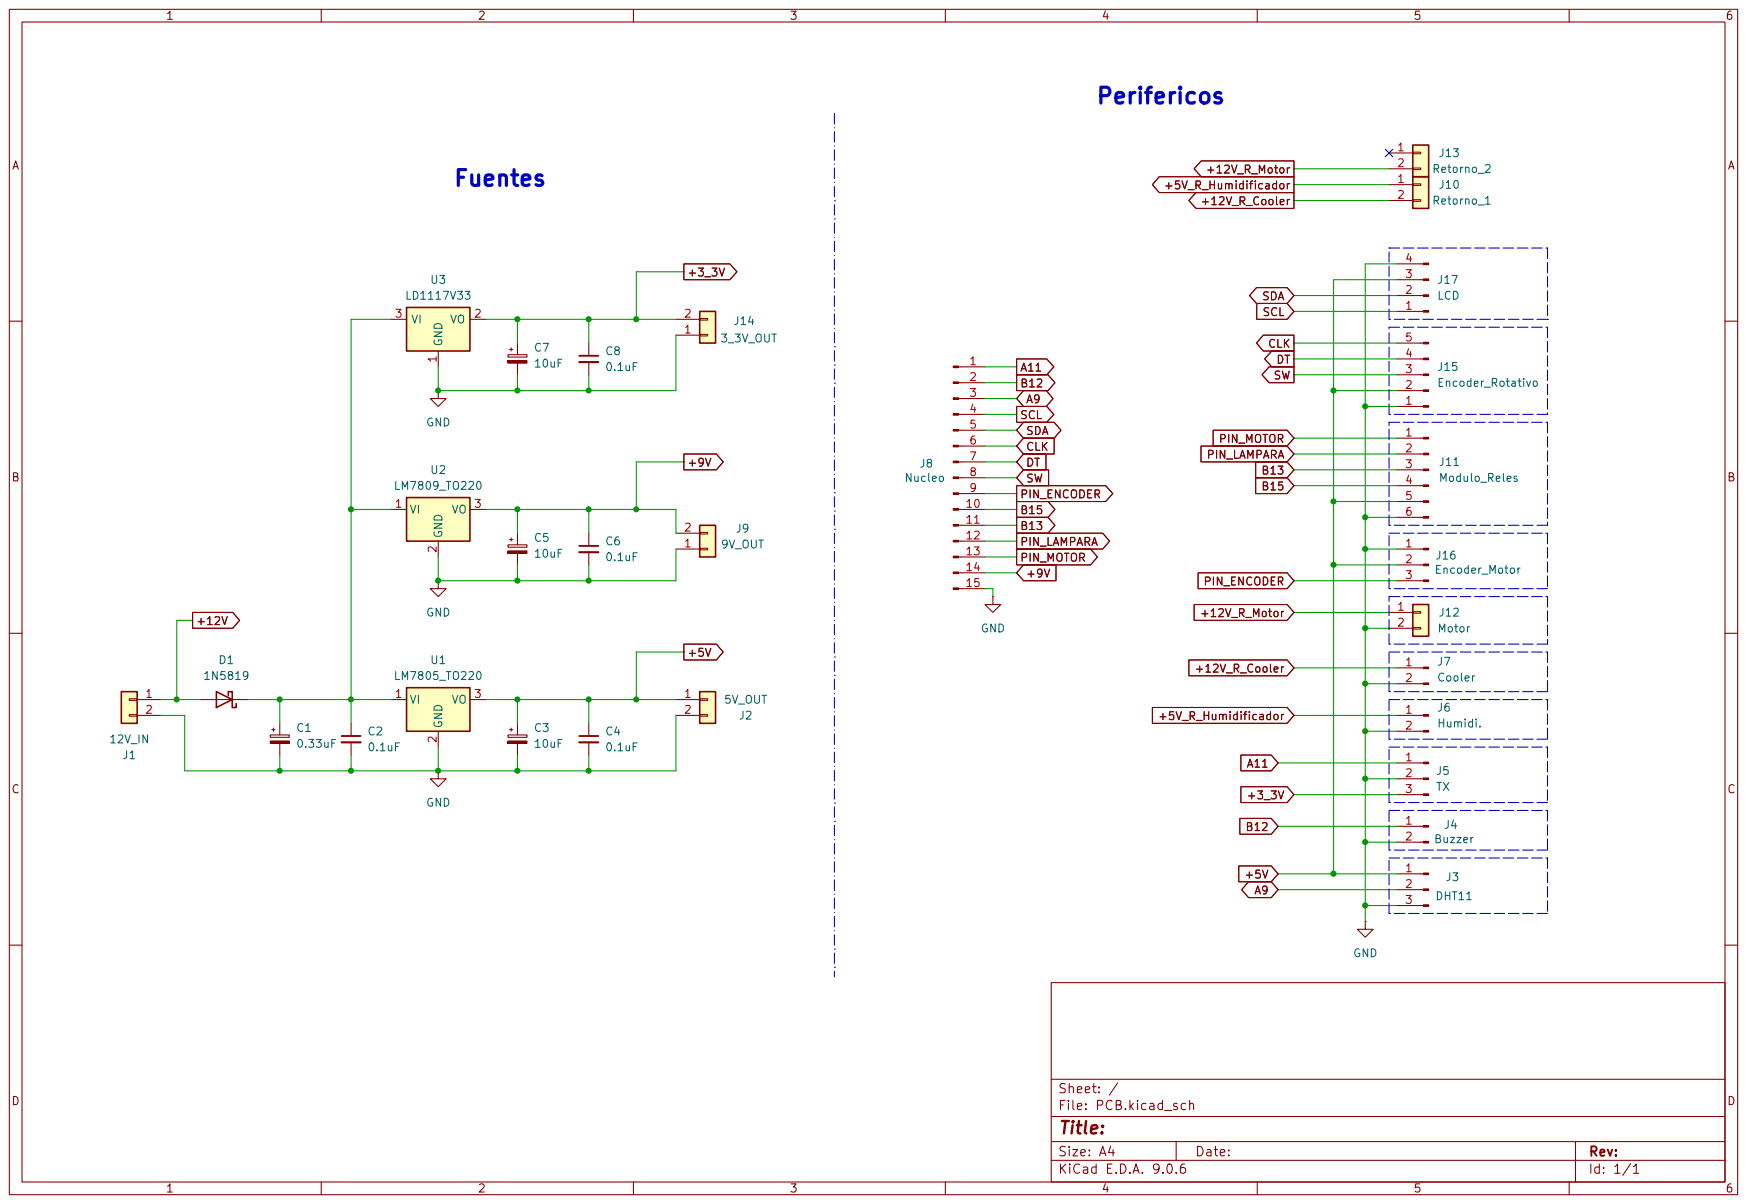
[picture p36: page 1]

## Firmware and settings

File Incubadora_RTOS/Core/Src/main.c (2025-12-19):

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
/* Includes ------------------------------------------------------------------*/
#include "main.h"
#include "cmsis_os.h"

/* USER CODE BEGIN Includes */
#include "FreeRTOS.h"
#include "task.h"
#include "queue.h"
#include "semphr.h"

#include "i2c-lcd.h"
#include "eeprom.h"
#include "utils.h"
#include "config.h"
#include "rele.h"
#include "dht11.h"

/* USER CODE END Includes */

I2C_HandleTypeDef hi2c1;

TIM_HandleTypeDef htim12;

UART_HandleTypeDef huart2;
UART_HandleTypeDef huart3;

osThreadId defaultTaskHandle;
/* USER CODE BEGIN PV */

TaskHandle_t menuTaskHandle;
TaskHandle_t debounceTaskHandle;
TaskHandle_t motorTaskHandle;
TaskHandle_t controlTaskHandle;
TaskHandle_t sensorTaskHandle;

QueueHandle_t menuQueueHandle;
SemaphoreHandle_t xDHTMutex;

// --- VARIABLES DE SISTEMA ---
volatile uint32_t pulsos_acumulados = 0;
uint16_t global_rpm = 0;
volatile uint8_t is_welcome = 1;

// --- VARIABLES DE CONTROL ---
float last_valid_temp = 0.0f;
float last_valid_hum = 0.0f;
uint32_t last_dht_read_time = 0;
HumidifierState_t hum_state = HUM_STATE_IDLE;
/* USER CODE END PV */

void SystemClock_Config(void);
static void MX_GPIO_Init(void);
static void MX_I2C1_Init(void);
static void MX_USART2_UART_Init(void);
static void MX_USART3_UART_Init(void);
static void MX_TIM12_Init(void);
void StartDefaultTask(void const * argument);

/* USER CODE BEGIN 0 */

/**
 * @brief Tarea principal de gestión de menú e interfaz de usuario.
 *
 * Esta tarea maneja:
 *  -
 *  -
 *  -
 *  -
 *
 * La comunicación con las ISR se realiza mediante una cola RTOS.
 *
 * @param argument Parámetro no utilizado
 */

void StartMenuTask(void *argument)
{
    /* Mensaje de bienvenida */
    if (is_welcome) {
        LCD_ShowWelcome("TDII: INCUBADORA");
        vTaskDelay(pdMS_TO_TICKS(1000));
        is_welcome = 0;
    }

    /* Inicializa la pantalla al arrancar la tarea */
    update_display();

    MenuEvent_t event;
    uint32_t last_draw_time = 0;   // Último refresco del LCD
    int needs_update = 0;          // Flag para redibujar pantalla

    /* Variables para actualización solo ante cambios (Dashboard) */
    float last_disp_temp = -999.0f;
    float last_disp_hum  = -999.0f;
    uint16_t last_disp_rpm = 9999;
    HumidifierState_t last_disp_hum_state = HUM_STATE_IDLE;
    uint8_t last_disp_day = 255;
    uint8_t last_disp_is_running = 255;
    uint8_t last_disp_hour = 255;

    for (;;)
    {
        /* Espera evento del menú (encoder / botón)
           Timeout de 200 ms para permitir refresco periódico del dashboard */
        if (xQueueReceive(menuQueueHandle, &event, pdMS_TO_TICKS(200)) == pdPASS)
        {
            MenuEvent_t initial_event = event;

            /* -------- BOTÓN: PRESIÓN LARGA (volver atrás) -------- */
            if (initial_event == BUTTON_LONG_PRESS) {
                // Si estamos en cualquier sub-menú de edición o test, volvemos al menú principal
                if (current_ui_mode == UI_MODE_TEST_MENU ||
                    current_ui_mode == UI_MODE_CONFIG_EDIT ||
                    current_ui_mode == UI_MODE_CONFIG_GLOBAL ||
                    current_ui_mode == UI_MODE_CONFIG_TIME ||
                    current_ui_mode == UI_MODE_CONFIG_SELECT)
                {
                    current_ui_mode = UI_MODE_MAIN_MENU;
                }
                else if (current_ui_mode == UI_MODE_MAIN_MENU) {
                    current_ui_mode = UI_MODE_DASHBOARD;
                }

                needs_update = 1;
                continue; // Saltar el resto del bucle
            }

            /* -------- PROCESAMIENTO DE MOVIMIENTO -------- */
            int8_t net_movement = 0;
            int button_pressed = 0;

            if (initial_event == ENCODER_RIGHT) net_movement++;
            else if (initial_event == ENCODER_LEFT) net_movement--;
            else if (initial_event == BUTTON_PRESS) button_pressed = 1;

            /* Acumula eventos rápidos del encoder (anti-lag UI) */
            int batch_limit = 20;
            while (batch_limit-- > 0 && xQueueReceive(menuQueueHandle, &event, 0) == pdPASS)
            {
                if (event == ENCODER_RIGHT) net_movement++;
                else if (event == ENCODER_LEFT) net_movement--;
            }

            /* ================= LÓGICA DE INTERFAZ ================= */

            /* -------- DASHBOARD -------- */
            if (current_ui_mode == UI_MODE_DASHBOARD) {
                if (button_pressed) {
                    current_ui_mode = UI_MODE_MAIN_MENU;
                    selected_item = 0;
                    needs_update = 1;
                }
            }

            /* -------- MENÚ PRINCIPAL -------- */
            else if (current_ui_mode == UI_MODE_MAIN_MENU) {

                if (net_movement != 0) {
                    int16_t new_pos = selected_item + net_movement;
                    selected_item = ((new_pos % menu_size) + menu_size) % menu_size;

                    if (selected_item >= menu_top_item + LCD_ROWS)
                        menu_top_item = selected_item - (LCD_ROWS - 1);
                    else if (selected_item < menu_top_item)
                        menu_top_item = selected_item;

                    needs_update = 1;
                }

                if (button_pressed) {
                    if (selected_item == 1) { // INICIAR / PAUSAR
                        /* OPTIMIZACIÓN: Calcular y Guardar UNA sola vez */
                        if (sysData.is_running) {
                            // Pausando: Calcular tiempo transcurrido y sumar
                            uint32_t current_session_min = (HAL_GetTick() - sysData.last_boot_tick) / 60000U;
                            sysData.saved_timestamp += current_session_min;
                            sysData.is_running = 0;
                        } else {
                            // Iniciando: Resetear tick de referencia
                            sysData.is_running = 1;
                            sysData.last_boot_tick = HAL_GetTick();
                        }
                        // Guardado único para no congelar la UI dos veces
                        Save_Config_To_Flash();
                    }
                    else if (selected_item == 2) { // CONFIGURACION
                        current_ui_mode = UI_MODE_CONFIG_SELECT;
                        config_sel_index = 0;
                        config_top_index = 0;
                    }
                    else if (selected_item == 3) { // TEST
                        current_ui_mode = UI_MODE_TEST_MENU;
                        test_selected_item = 0;
                    }
                    else { // VOLVER / VER SENSORES
                        current_ui_mode = UI_MODE_DASHBOARD;
                    }
                    needs_update = 1;
                }
            }

            /* -------- MENÚ DE TEST -------- */
            else if (current_ui_mode == UI_MODE_TEST_MENU) {
                if (net_movement != 0) {
                    int16_t new_pos = test_selected_item + net_movement;
                    test_selected_item = ((new_pos % test_menu_size) + test_menu_size) % test_menu_size;

                    if (test_selected_item >= test_top_item + LCD_ROWS)
                        test_top_item = test_selected_item - (LCD_ROWS - 1);
                    else if (test_selected_item < test_top_item)
                        test_top_item = test_selected_item;

                    needs_update = 1;
                }
                if (button_pressed) {
                    toggle_output(test_selected_item);
                    needs_update = 1;
                }
            }

            /* -------- SELECCIÓN DE CONFIGURACIÓN -------- */
            else if (current_ui_mode == UI_MODE_CONFIG_SELECT) {
                if (net_movement != 0) {
                    int16_t new_pos = config_sel_index + net_movement;
                    config_sel_index = ((new_pos % config_menu_sz) + config_menu_sz) % config_menu_sz;

                    if (config_sel_index >= config_top_index + LCD_ROWS)
                        config_top_index = config_sel_index - (LCD_ROWS - 1);
                    else if (config_sel_index < config_top_index)
                        config_top_index = config_sel_index;

                    needs_update = 1;
                }

                if (button_pressed) {
                    if (config_sel_index <= 1) { // Desarrollo o Eclosión
                        sysData.current_stage_idx = config_sel_index;
                        current_ui_mode = UI_MODE_CONFIG_EDIT;
                        config_item = 0;
                        is_editing_val = 0;
                    }
                    else if (config_sel_index == 2) { // Ciclo Total
                        current_ui_mode = UI_MODE_CONFIG_GLOBAL;
                        config_item = 0;
                        is_editing_val = 0;
                    }
                    else if (config_sel_index == 3) { // Ajustar Tiempo
                        current_ui_mode = UI_MODE_CONFIG_TIME;
                        config_item = 0;
                        is_editing_val = 0;
                        // Cargar valores actuales en variables temporales
                        edit_day  = Get_Current_Day();
                        if (edit_day == 0) edit_day = 1;
                        edit_hour = Get_Current_Hour();
                        edit_min  = Get_Current_Minute();
                    }
                    else { // Volver
                        current_ui_mode = UI_MODE_MAIN_MENU;
                    }
                    needs_update = 1;
                }
            }

            /* -------- CONFIGURACIÓN: EDICIÓN DE ETAPA (LO QUE FALTABA) -------- */
            else if (current_ui_mode == UI_MODE_CONFIG_EDIT) {
                StageConfig_t *st = &sysData.stages[sysData.current_stage_idx];

                if (button_pressed) {
                    if (config_item == 4) { // [SALIR]
                        Save_Config_To_Flash();
                        current_ui_mode = UI_MODE_CONFIG_SELECT;
                    } else {
                        is_editing_val = !is_editing_val;
                    }
                    needs_update = 1;
                }

                if (net_movement != 0) {
                    if (!is_editing_val) {
                        config_item += net_movement;
                        if (config_item < 0) config_item = 4;
                        if (config_item > 4) config_item = 0;
                    } else {
                        switch(config_item) {
                            case 0: // Fin Día
                                st->end_day += net_movement;
                                if(st->end_day < 1) st->end_day = 1;
                                break;
                            case 1: // Temp
                                st->temp_target += (net_movement * 0.1f);
                                if(st->temp_target > 42.0f) st->temp_target = 42.0f; // Límites
                                if(st->temp_target < 20.0f) st->temp_target = 20.0f;
                                break;
                            case 2: // Hum
                                st->hum_target += (float)net_movement;
                                if(st->hum_target > 90.0f) st->hum_target = 90.0f;
                                if(st->hum_target < 20.0f) st->hum_target = 20.0f;
                                break;
                            case 3: // Motor
                                if(net_movement != 0) st->motor_on = !st->motor_on;
                                break;
                        }
                    }
                    needs_update = 1;
                }
            }

            /* -------- CONFIGURACIÓN: GLOBAL (LO QUE FALTABA) -------- */
            else if (current_ui_mode == UI_MODE_CONFIG_GLOBAL) {
                if (button_pressed) {
                    if (config_item == 1) { // [GUARDAR]
                        Save_Config_To_Flash();
                        current_ui_mode = UI_MODE_CONFIG_SELECT;
                    } else {
                        is_editing_val = !is_editing_val;
                    }
                    needs_update = 1;
                }

                if (net_movement != 0) {
                    if (!is_editing_val) {
                        config_item += net_movement;
                        if (config_item < 0) config_item = 1;
                        if (config_item > 1) config_item = 0;
                    } else {
                        if (config_item == 0) { // Total Días
                            sysData.total_days += net_movement;
                            if (sysData.total_days < 1) sysData.total_days = 1;
                        }
                    }
                    needs_update = 1;
                }
            }

            /* -------- CONFIGURACIÓN: TIEMPO -------- */
            else if (current_ui_mode == UI_MODE_CONFIG_TIME) {
                if (button_pressed) {
                    if (config_item == 3) { // [GUARDAR]
                        uint32_t new_total_mins =
                            ((uint32_t)(edit_day - 1) * 1440) +
                            ((uint32_t)edit_hour * 60) +
                            (uint32_t)edit_min;

                        sysData.saved_timestamp = new_total_mins;
                        sysData.last_boot_tick = HAL_GetTick();
                        Save_Config_To_Flash();
                        current_ui_mode = UI_MODE_CONFIG_SELECT;
                    } else {
                        is_editing_val = !is_editing_val;
                    }
                    needs_update = 1;
                }
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
int main(void)
{
  /* MCU Configuration--------------------------------------------------------*/

  /* Reset of all peripherals, Initializes the Flash interface and the Systick. */
  HAL_Init();

  /* Configure the system clock */
  SystemClock_Config();

  /* Initialize all configured peripherals */
  MX_GPIO_Init();
  MX_I2C1_Init();
  MX_USART2_UART_Init();
  MX_USART3_UART_Init();
  MX_TIM12_Init();


  /* USER CODE BEGIN 2 */
  HAL_GPIO_WritePin(LD2_GPIO_Port, LD2_Pin, GPIO_PIN_SET);

  Enable_Internal_Pullups(); // Anti-ruido I2C
  I2C_Scan();                // Escaneo
  HD44780_Init(LCD_ROWS);
  // Cargar configuración guardada
  Load_Config_From_Flash();

  DHT11_Init();
  RELES_Init();
  /* USER CODE END 2 */

  /* USER CODE BEGIN RTOS_MUTEX */
  xDHTMutex = xSemaphoreCreateMutex();
  /* USER CODE END RTOS_MUTEX */

  /* USER CODE BEGIN RTOS_QUEUES */
  menuQueueHandle = xQueueCreate(32, sizeof(uint32_t));
  /* USER CODE END RTOS_QUEUES */

  /* Create the thread(s) */
  /* definition and creation of defaultTask */
  osThreadDef(defaultTask, StartDefaultTask, osPriorityLow, 0, 128);
  defaultTaskHandle = osThreadCreate(osThread(defaultTask), NULL);

  /* USER CODE BEGIN RTOS_THREADS */
  xTaskCreate(StartMenuTask, "Menu", 1024, NULL, osPriorityRealtime, &menuTaskHandle);
  xTaskCreate(StartDebounceTask, "Debounce", 128, NULL, osPriorityNormal, &debounceTaskHandle);
  xTaskCreate(StartMotorTask, "Motor", 128, NULL, osPriorityNormal, &motorTaskHandle);
  xTaskCreate(StartControlTask, "Control", 512, NULL, osPriorityNormal, &controlTaskHandle);
  xTaskCreate(StartSensorTask, "Sensor", 1024, NULL, osPriorityAboveNormal, &sensorTaskHandle);

  /* USER CODE END RTOS_THREADS */

  /* Start scheduler */
  osKernelStart();

  /* We should never get here as control is now taken by the scheduler */
  /* Infinite loop */
  /* USER CODE BEGIN WHILE */
  while (1)
  {
    /* USER CODE END WHILE */

    /* USER CODE BEGIN 3 */
  }
  /* USER CODE END 3 */
}

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
/* USER CODE BEGIN 4 */

void vApplicationStackOverflowHook(TaskHandle_t xTask, char *pcTaskName)
{
   while(1)
   {
      HAL_GPIO_TogglePin(LD2_GPIO_Port, LD2_Pin);
      HAL_Delay(50);
   }
}

/**
 * @brief Callback de interrupción externa por GPIO (EXTI).
 *
 * Esta función es llamada automáticamente por la HAL cuando ocurre
 * una interrupción externa en un pin configurado como EXTI.
 *
 * Maneja dos funcionalidades:
 *  - Conteo de pulsos del sensor de motor (RPM)
 *  - Decodificación de un encoder rotativo en cuadratura (A/B)
 *
 * @param GPIO_Pin Pin que generó la interrupción.
 */
void HAL_GPIO_EXTI_Callback(uint16_t GPIO_Pin)
{
	/* ================= SENSOR DE MOTOR ================= */
	    // Si la interrupción proviene del sensor de RPM del motor
	    if (GPIO_Pin == MOTOR_SENSOR_PIN) {
	        // Incrementamos ambas variables:
	        pulsos_acumulados++;
	        return;
	    }

    /* ================= ENCODER ROTATIVO ================= */

    // Si la interrupción proviene de cualquiera de las fases del encoder
    if (GPIO_Pin == ENCODER_A_Pin || GPIO_Pin == ENCODER_B_Pin) {

        // Último estado válido del encoder (AB)
        static uint8_t last_state = 0;

        // Contador interno para acumular transiciones
        // 4 transiciones = 1 paso mecánico del encoder
        static int8_t counter = 0;

        // Leer estados actuales de las señales A y B
        uint8_t state_A = HAL_GPIO_ReadPin(ENCODER_A_GPIO_Port, ENCODER_A_Pin);
        uint8_t state_B = HAL_GPIO_ReadPin(ENCODER_B_GPIO_Port, ENCODER_B_Pin);

        // Combinar A y B en un estado de 2 bits: [A B]
        uint8_t current_state = (state_A << 1) | state_B;

        // Ignorar si el estado no cambió (rebotes o ruido)
        if (current_state == last_state) return;

        /*
         * Tabla de transición del encoder en cuadratura.
         * Index = (last_state << 2) | current_state
         * Valores:
         *  +1 -> giro horario
         *  -1 -> giro antihorario
         *   0 -> transición inválida o ruido
         */
        const int8_t transition_table[16] = {
             0, -1,  1,  0,
             1,  0,  0, -1,
            -1,  0,  0,  1,
             0,  1, -1,  0,
        };

        // Obtener la transición correspondiente
        int8_t transition =
            transition_table[(last_state << 2) | current_state];

        // Si la transición es válida
        if (transition != 0) {

            // Acumular transición
            counter += transition;

            // 4 transiciones positivas → un paso a la derecha
            if (counter >= 4) {
                MenuEvent_t event = ENCODER_RIGHT;

                // Enviar evento a la cola del menú
                osMessagePut(menuQueueHandle, (uint32_t)event, 0);

                // Ajustar contador
                counter -= 4;
            }
            // 4 transiciones negativas → un paso a la izquierda
            else if (counter <= -4) {
                MenuEvent_t event = ENCODER_LEFT;

                // Enviar evento a la cola del menú
                osMessagePut(menuQueueHandle, (uint32_t)event, 0);

                // Ajustar contador
                counter += 4;
            }
        }

        // Actualizar el último estado del encoder
        last_state = current_state;
    }
}


/* USER CODE END 4 */

/* USER CODE BEGIN Header_StartDefaultTask */
/**
  * @brief  Function implementing the defaultTask thread.
  * @param  argument: Not used
  * @retval None
  */
/* USER CODE END Header_StartDefaultTask */
void StartDefaultTask(void const * argument)
{
  /* USER CODE BEGIN 5 */
  /* Infinite loop */
  for(;;)
  {
    osDelay(1);
  }
  /* USER CODE END 5 */
}

 /**
  * @brief  Period elapsed callback in non blocking mode
  * @note   This function is called  when TIM6 interrupt took place, inside
  * HAL_TIM_IRQHandler(). It makes a direct call to HAL_IncTick() to increment
  * a global variable "uwTick" used as application time base.
  * @param  htim : TIM handle
  * @retval None
  */
void HAL_TIM_PeriodElapsedCallback(TIM_HandleTypeDef *htim)
{
  if (htim->Instance == TIM6) {
    HAL_IncTick();
  }
}

/**
  * @brief  This function is executed in case of error occurrence.
  * @retval None
  */
void Error_Handler(void)
{
  /* USER CODE BEGIN Error_Handler_Debug */
  /* User can add his own implementation to report the HAL error return state */
  __disable_irq();
  while (1)
  {
  }
  /* USER CODE END Error_Handler_Debug */
}

#ifdef  USE_FULL_ASSERT
/**
  * @brief  Reports the name of the source file and the source line number
  *         where the assert_param error has occurred.
  * @param  file: pointer to the source file name
  * @param  line: assert_param error line source number
  * @retval None
  */
void assert_failed(uint8_t *file, uint32_t line)
{
  /* USER CODE BEGIN 6 */
  /* User can add his own implementation to report the file name and line number,
     ex: printf("Wrong parameters value: file %s on line %d\r\n", file, line) */
  /* USER CODE END 6 */
}
#endif /* USE_FULL_ASSERT */

/************************ (C) COPYRIGHT STMicroelectronics *****END OF FILE****/

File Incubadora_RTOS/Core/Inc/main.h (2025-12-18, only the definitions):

#define B1_Pin GPIO_PIN_13
#define B1_GPIO_Port GPIOC
#define ENCODER_A_Pin GPIO_PIN_0
#define ENCODER_A_GPIO_Port GPIOC
#define ENCODER_B_Pin GPIO_PIN_1
#define ENCODER_B_GPIO_Port GPIOC
#define ENCODER_B_EXTI_IRQn EXTI1_IRQn
#define USART_TX_Pin GPIO_PIN_2
#define USART_TX_GPIO_Port GPIOA
#define USART_RX_Pin GPIO_PIN_3
#define USART_RX_GPIO_Port GPIOA
#define LD2_Pin GPIO_PIN_5
#define LD2_GPIO_Port GPIOA
#define ENCODER_SW_Pin GPIO_PIN_0
#define ENCODER_SW_GPIO_Port GPIOB
#define LAMPARA_Pin GPIO_PIN_10
#define LAMPARA_GPIO_Port GPIOB
#define BUZZER_Pin GPIO_PIN_12
#define BUZZER_GPIO_Port GPIOB
#define HUMIDIFICADOR_Pin GPIO_PIN_8
#define HUMIDIFICADOR_GPIO_Port GPIOA
#define COOLER_Pin GPIO_PIN_9
#define COOLER_GPIO_Port GPIOA
#define DHT11_Pin GPIO_PIN_11
#define DHT11_GPIO_Port GPIOA
#define TMS_Pin GPIO_PIN_13
#define TMS_GPIO_Port GPIOA
#define TCK_Pin GPIO_PIN_14
#define TCK_GPIO_Port GPIOA
#define SWO_Pin GPIO_PIN_3
#define SWO_GPIO_Port GPIOB
#define MOTOR_Pin GPIO_PIN_4
#define MOTOR_GPIO_Port GPIOB

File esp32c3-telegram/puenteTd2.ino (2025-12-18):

#include <Arduino.h>
#include <WiFi.h>
#include <WiFiManager.h>      
#include <WiFiClientSecure.h> 

// ---------------------------------------------------------------------------
// IMPORTANTE: ESTE CÓDIGO REQUIERE ARDUINO JSON VERSIÓN 6.21.5
// Si tienes la versión 7.x.x, ve al Gestor de Librerías, busca ArduinoJson
// y selecciona la versión 6.21.5 para instalarla (Downgrade).
// ---------------------------------------------------------------------------
#include <CTBot.h>            

// ==========================================
// CONFIGURACIÓN DE USUARIO
// ==========================================
const char* token = "8289483635:AAEaHNfAq4bn54nVXZgFgaWna9pJ-2CTpdc";

// SOLUCIÓN AL ERROR DE COMPILACIÓN:
// Definimos el ID como Texto (String) para evitar el error de "decrement operand".
// El código lo convertirá a número automáticamente en el setup.
String chatID_Texto = "-5018890121"; 

// ==========================================
// HARDWARE
// ==========================================
#define RX_PIN 20             
#define TX_PIN 21             
#define LED_PIN 8             
#define TRIGGER_PIN 9         

// ==========================================
// OBJETOS GLOBALES
// ==========================================
HardwareSerial SerialPort(1); 
CTBot myBot;                  
WiFiManager wm;
bool wifiConnected = false;
int64_t targetChatID; // Aquí se guardará el ID numérico convertido

// Configuración IP para Portal (Estilo HH3)
IPAddress apIP(8, 8, 8, 8);
IPAddress apGateway(8, 8, 8, 8);
IPAddress apSubnet(255, 255, 255, 0);

// ==========================================
// PROTOTIPOS
// ==========================================
void configModeCallback(WiFiManager *myWiFiManager);
void sendToTelegram(String text);

// ==========================================
// SETUP
// ==========================================
void setup() {
  Serial.begin(115200);
  SerialPort.begin(115200, SERIAL_8N1, RX_PIN, TX_PIN);
  
  pinMode(LED_PIN, OUTPUT);
  pinMode(TRIGGER_PIN, INPUT_PULLUP);

  // --- CONVERSIÓN DEL ID (Solución al error) ---
  // strtoll convierte el String a un número de 64 bits (long long) de forma segura
  targetChatID = strtoll(chatID_Texto.c_str(), NULL, 10);
  
  Serial.println("\n--- BRIDGE TELEGRAM (CTBot Version) ---");
  Serial.print("Target ID (Texto): ");
  Serial.println(chatID_Texto);
  
  // CORRECCIÓN: Usamos printf con %lld para ver el número de 64 bits completo.
  Serial.printf("Target ID Numérico: %lld\n", targetChatID); 

  // Configuración Portal WiFi
  wm.setAPCallback(configModeCallback);
  wm.setAPStaticIPConfig(apIP, apGateway, apSubnet); 
  wm.setConnectTimeout(30); 

  if (!wm.autoConnect("ESP32-Telegram-Bridge")) {
    Serial.println("Fallo WiFi. Reiniciando...");
    delay(3000);
    ESP.restart();
  }

  Serial.println("WiFi Conectado.");
  
  // CTBot Setup
  myBot.setTelegramToken(token);
  myBot.useDNS(true); 

  Serial.print("Probando conexión Telegram...");
  if (myBot.testConnection()) {
    Serial.println(" OK!");
    wifiConnected = true;
    digitalWrite(LED_PIN, HIGH); 
    
    // Mensaje de inicio
    String msg = "🟢 Sistema Online.\nIP: " + WiFi.localIP().toString();
    myBot.sendMessage(targetChatID, msg);
  } else {
    Serial.println(" FALLO. (Revisa Token, Internet o Versión de JSON)");
    wifiConnected = false;
  }
}

// ==========================================
// LOOP
// ==========================================
void loop() {
  // 1. Heartbeat
  if (!wifiConnected) {
    static unsigned long lastBlink = 0;
    if (millis() - lastBlink > 500) {
      lastBlink = millis();
      digitalWrite(LED_PIN, !digitalRead(LED_PIN));
    }
  }

  // 2. Reset WiFi
  if (digitalRead(TRIGGER_PIN) == LOW) {
    delay(50); 
    if (digitalRead(TRIGGER_PIN) == LOW) {
      unsigned long startPress = millis();
      while (digitalRead(TRIGGER_PIN) == LOW) {
        if (millis() - startPress > 3000) {
          Serial.println("!!! BORRANDO WIFI !!!");
          for(int i=0; i<5; i++) { digitalWrite(LED_PIN, !digitalRead(LED_PIN)); delay(100); }
          wm.resetSettings(); 
          ESP.restart();      
        }
      }
    }
  }

  // 3. Puente UART (Recibir datos del cable y enviar a Telegram)
  if (SerialPort.available() > 0) {
    String receivedData = SerialPort.readString();
    receivedData.trim(); 
    
    if (receivedData.length() > 0) {
      Serial.print("UART >> "); Serial.println(receivedData);
      sendToTelegram("📩 " + receivedData);
    }
  }

  // 4. Comandos de Telegram
  // Verificamos si hay mensajes nuevos para comandos como /test
  TBMessage msg;
  if (myBot.getNewMessage(msg)) {
    
    // Usamos startsWith para detectar "/test" incluso si escriben "/test@NombreBot"
    if (msg.text.startsWith("/test")) {
        Serial.println("Comando /test recibido.");
        
        // MODIFICACIÓN: Respondemos al ID DEL GRUPO (targetChatID) 
        // en lugar de al usuario privado (msg.sender.id).
        // Así confirmamos en el grupo que el bot está activo.
        String respuesta = "✅ Estado: ACTIVO\n";
        respuesta += "📡 Escuchando en Grupo: " + chatID_Texto; // Usamos el String original para evitar errores de visualización
        
        myBot.sendMessage(targetChatID, respuesta);
    }
  }
}

// ==========================================
// FUNCIONES AUXILIARES
// ==========================================
void configModeCallback(WiFiManager *myWiFiManager) {
  Serial.println("MODO AP: Esperando configuración WiFi...");
  Serial.println(WiFi.softAPIP()); 
  digitalWrite(LED_PIN, HIGH); 
}

void sendToTelegram(String text) {
  if (wifiConnected) {
    digitalWrite(LED_PIN, LOW); delay(50); digitalWrite(LED_PIN, HIGH);
    myBot.sendMessage(targetChatID, text);
  } else {
    Serial.println("Error: Sin conexión Telegram");
  }
}

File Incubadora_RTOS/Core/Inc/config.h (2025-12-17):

/*
 * config.h
 *
 *  Created on: 12 dic. 2025
 *      Author: Alexander
 */
#include "main.h"

#ifndef INC_CONFIG_H_
#define INC_CONFIG_H_

#define MOTOR_SENSOR_PIN	GPIO_PIN_0
#define MOTOR_SENSOR_PORT	GPIOA

#define DEBOUNCE_POLL_RATE_MS   5
#define DEBOUNCE_THRESHOLD      4
#define LONG_PRESS_MS           2000
#define LONG_PRESS_TICKS        (LONG_PRESS_MS / DEBOUNCE_POLL_RATE_MS)

#define ENCODER_SLOTS           20
#define MOTOR_CALC_INTERVAL_MS  1000

#define DHT_READ_INTERVAL_MS    30000   // Leer sensor cada 30 seg
#define CONTROL_LOOP_MS         1000    // Recalcular lógica cada 1 seg
#define HUM_DOSE_TIME_MS        10000   // Humidificador ON 10 seg
#define HUM_COOLDOWN_TIME_MS    300000  // Espera 5 min

//ETAPA 1 -> Hasta los primeros 18 dias de incubacion.
//ETAPA 2 -> Desde el dia 18 hasta el dia 21.

#define	TEMP_ETAPA1_MAX_CRITICA	40
#define	TEMP_ETAPA1_MAX_TOLERABLE	38
#define	TEMP_ETAPA1_MIN_TOLERABLE	37
#define	TEMP_ETAPA1_MIN_CRITICA	35

#define	TEMP_ETAPA2_MAX_CRITICA	38
#define	TEMP_ETAPA2_MAX_TOLERABLE	36
#define	TEMP_ETAPA2_MIN_TOLERABLE	35
#define	TEMP_ETAPA2_MIN_CRITICA	33

#define	HUMEDAD_ETAPA1_MAX_CRITICA	75
#define	HUMEDAD_ETAPA1_MAX_TOLERABLE	60
#define	HUMEDAD_ETAPA1_MIN_TOLERABLE	55
#define	HUMEDAD_ETAPA1_MIN_CRITICA	40

#define	HUMEDAD_ETAPA2_MAX_CRITICA	80
#define	HUMEDAD_ETAPA2_MAX_TOLERABLE	75
#define	HUMEDAD_ETAPA2_MIN_TOLERABLE	70
#define	HUMEDAD_ETAPA2_MIN_CRITICA	60

#define TIEMPO_ALARMA_MS	1800000	//30 min
#define TIEMPO_ALARMA_CRITICA_MS	3600000	//1 hora

#endif /* INC_CONFIG_H_ */

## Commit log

2025-08-21 Proyecto para Blue Pill
2025-08-21 Carpeta para archivos comunes
2025-08-21 Manuales de los componentes
2025-08-21 Manuales de componentes
2025-08-25 reference manual stm32f103c8t6
2025-08-29 Driver humedad_v1 malo pero que anda
    [modulo_DHT11 Debug.cfg]
2025-10-18 progreso del sensor de temperatura
    [ADC_PT100x Debug.cfg]
2025-11-12 Codigo Bluepill telegram
    [Envio_datos_telegram Debug.cfg]
2025-11-26 Proyecto con RELE, DHT11, COMU, LOGICA
    [modulo_DHT11 Debug.cfg]
2025-11-26 Se puede cargar el main con arduino IDE
2025-11-26 esp32 y reles
2025-11-29 Se cargo el modelo de la incubadora para impresion 3D
    [PCB.kicad_pcb, PCB.kicad_sch, base_huevos.stl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]
2025-11-30 Actualizacion de PCB y esquematico
    [PCB.kicad_pcb, PCB.kicad_sch]
2025-12-01 Actualizacion del PCB
    [PCB.kicad_pcb]
2025-12-01 Actualizacion del esquematico
    [PCB.kicad_sch]
2025-12-10 Actualizacion del modelo 3D
    [Grilla.stl, Grilla_ventana.stl, Marco_ventana.stl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]
2025-12-10 Se actualiza PCB y se agrega BOM interactivo
    [PCB.csv, PCB2.kicad_pcb]
2025-12-11 actualizo el modulo dht
    [ADC_PT100x Debug.cfg, Buzzer.cfg, modulo_DHT11 Debug.cfg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]
2025-12-11 DHT funcional, listo parar incorporar al proyecto
    [modulo_DHT11_v2_REMIX Debug.cfg]
2025-12-12 Se borraron archivos innecesarios
    [ADC_PT100x Debug.cfg, modulo_DHT11 Debug.cfg]
2025-12-12 proyecto de Franco
2025-12-12 elimino para resubir
2025-12-12 resubiendo como la espuma
2025-12-14 Actualizacion del proyecto general: Se limpio el main, se agregaron nuevos archivos para separar el codigo contenido en el main, se agrego archivos de configuracion genera
2025-12-14 Se integra la logica del DHT11 al proyecto general
2025-12-15 Upgrade modelo 3D de la incubadora
    [Base.stl, Soporte_motor.stl, carrousel.stl]
2025-12-17 Actualizacion del proyecto general
    [modulo_DHT11 Debug.cfg]
2025-12-18 Codigo ESP32

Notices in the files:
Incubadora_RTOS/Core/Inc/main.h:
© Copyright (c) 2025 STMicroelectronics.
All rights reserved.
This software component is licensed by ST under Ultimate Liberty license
